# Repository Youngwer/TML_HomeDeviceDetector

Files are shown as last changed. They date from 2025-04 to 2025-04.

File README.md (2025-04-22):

# Home Device Detector

This project implements an embedded sound recognition system that assists Deaf and hard of hearing (DHH) individuals🧏 by detecting and classifying critical household sounds (smoke alarms and doorbells) and providing visual alerts through LEDs.

## Project Overview

The Home Device Detector addresses accessibility barriers for DHH individuals in smart homes by developing a TinyML-based embedded system that can:

- Detect critical household sound events in real-time⏰
- Classify between normal ambient sounds, doorbell rings🔔, and smoke alarms🚨
- Provide immediate visual feedback through color-coded LED indicators💡
- Process audio locally for enhanced privacy and reduced latency

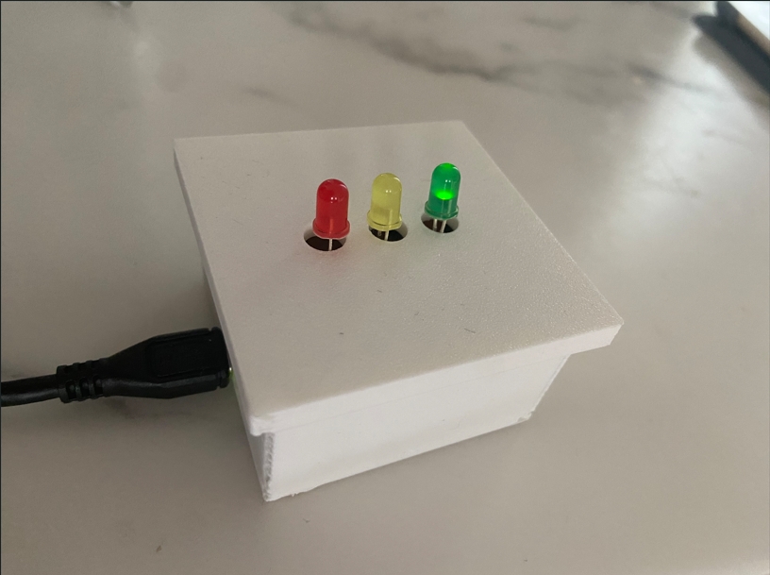
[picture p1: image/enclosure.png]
en


### Features

- Real-time detection of 3 sound categories:
  - Normal environmental sounds
  - Doorbell rings
  - Smoke alarms
- Visual feedback through LED indicators:
  - Green🟩 for normal environment
  - Yellow🟨 for doorbell alerts
  - Red🟥for smoke alarm detection
- Fast response time (within 2 seconds)
- Compact 3D-printed enclosure for easy placement
- Serial monitoring interface for debugging

## Hardware Requirements

- Arduino Nano 33 BLE Sense
- 3× LEDs (Green, Yellow, Red)
- 3× 220Ω resistors
- Breadboard or stripboard circuit connections
- 3D-printed enclosure (optional)
- USB cable for power and programming

## Software Dependencies and Resources

- Arduino IDE
- [Autodesk Fusion](https://www.autodesk.com/uk/products/fusion-360/overview?term=1-YEAR&tab=subscription) (for 3D modeling)
- [PrusaSlicer](https://www.prusa3d.com/page/prusaslicer_424/)(for 3D printing)
- [Edge Impulse](https://edgeimpulse.com/) Platform
- Librarys like [ArduinoBLE](https://docs.arduino.cc/libraries/arduinoble/) and [PDM.h](https://github.com/adafruit/Adafruit_ZeroPDM)
- Model library exported from Edge Impulse for [Home Device Detector](/ei-homedevicedetector-arduino-1.0.21.zip)

## Installation

1. Clone this repository:

   ```
   git clone https://github.com/Youngwer/TML_HomeDeviceDetector.git
   ```

2. Open the Arduino sketch [(`TML_HomeDeviceDetector.ino`)](/TML_HomeDeviceDetector/TML_HomeDeviceDetector.ino) in the Arduino IDE.

3. Install the required libraries through the Arduino IDE via:

Sketch > Include Library > Add .ZIP Library>ei-homedevicedetector-arduino-1.0.21.zip

4. The Edge Impulse model is already included in the repository as the `HomeDeviceDetector_inferencing` library. If you want to modify or retrain the model:

   - Create an account on [Edge Impulse](https://studio.edgeimpulse.com/)
   - Follow the instructions in the report to recreate the model
   - Export the model as an Arduino library
   - Replace the existing model files in the repository

5. Connect the hardware components according to the circuit diagram shown below:

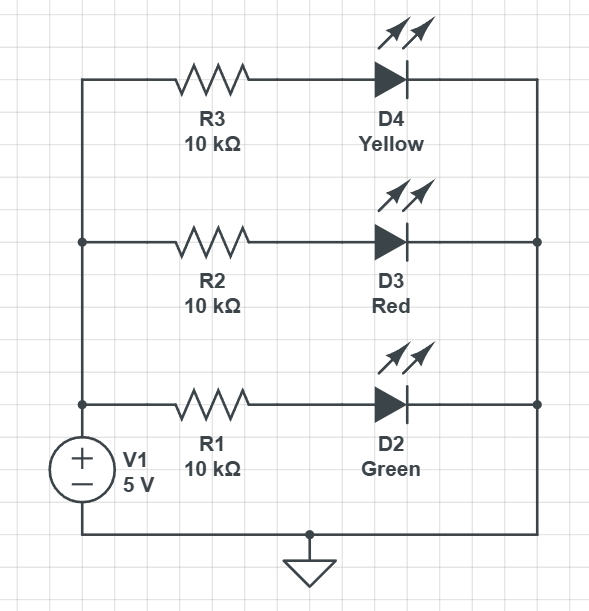
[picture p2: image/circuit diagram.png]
circuit diagram

   - Connect the Green LED to pin D2 through a 10kΩ resistor
   - Connect the Yellow LED to pin D3 through a 10kΩ resistor
   - Connect the Red LED to pin D4 through a 10kΩ resistor

6. Upload the sketch to your Arduino Nano 33 BLE Sense.

## Usage

Once the system is powered on and initialized:

1. The device will continuously monitor ambient sounds through the onboard microphone.
2. When a sound event is detected, the corresponding LED will illuminate:
   - Green LED: Normal environmental sounds
   - Yellow LED: Doorbell detection (with distinctive blinking pattern)
   - Red LED: Smoke alarm detection (with rapid blinking pattern)
3. Connect to the serial monitor (115200 baud) to view detailed classification results and debugging information.

## System Architecture

The system is implemented in a single Arduino sketch file:

- **TML_HomeDeviceDetector.ino** - Contains all functionality including audio capture, processing, inference, and LED control

This monolithic approach simplifies the codebase while still providing clear organization through different code sections and functions.

### Data Processing Pipeline

1. Continuous audio sampling through built-in microphone on the board
2. Pre-processing of audio data (windowing, normalization)
3. Feature extraction using Mel-Frequency Energy (MFE) spectrograms
4. Inference using the quantized TensorFlow Lite model
5. Classification of sound events based on confidence thresholds
6. Visual feedback through LED indicators

Below is a diagram show how the system work.

workflow
## Model Training

The model was trained using Edge Impulse with the following workflow:

1. Data collection from multiple sources:
   - Online audio repositories for doorbell and smoke alarm sounds
   - Smartphone recordings for ambient environmental sounds

2. Dataset preparation with balanced class distribution:
   - Smoke alarm: 1 minute 42 seconds
   - Doorbell sounds: 1 minute 50 seconds
   - Normal environmental audio: 1 minute 56 seconds
   - 80:20 train/test split

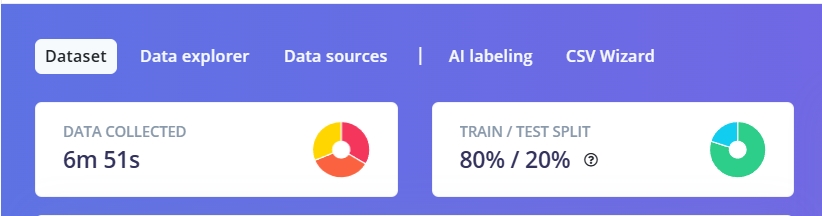
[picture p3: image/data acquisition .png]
dataset


3. Feature extraction using MFE spectrograms:
   - Window size: 1000ms
   - Window increase: 500ms
   - Sampling rate: 16kHz
   - 48 filters and 2048 FFT length

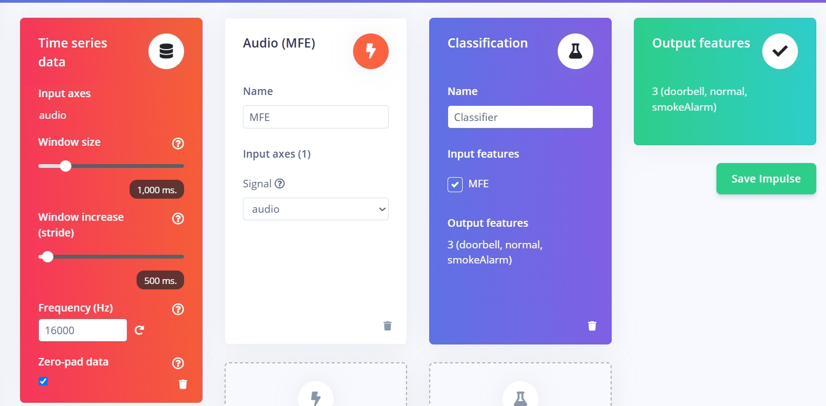
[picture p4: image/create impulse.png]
MFE

4. Neural network architecture:
   - Convolutional layers with optimized filter configurations
   - Dropout regularization to prevent overfitting
   - Dense layers for final classification

neural network
5. Model optimization and quantization:
   - Final accuracy: 94.9% (training), 90.32% (testing)
   - Model size optimized for Arduino deployment
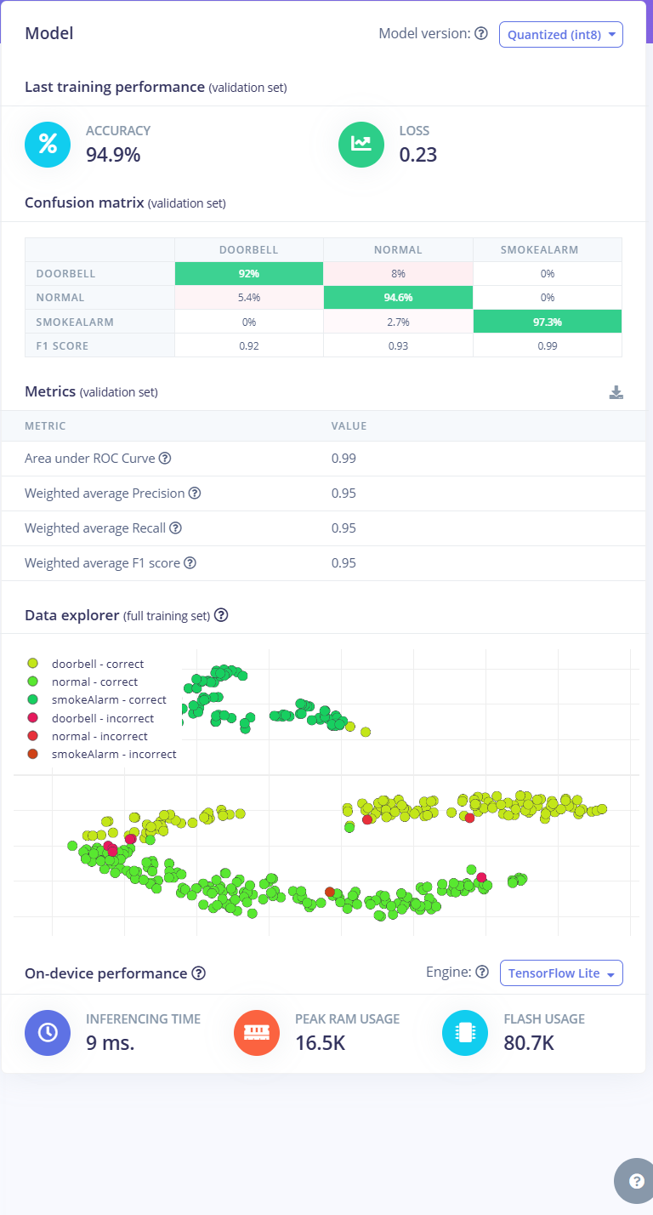
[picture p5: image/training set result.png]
training set result


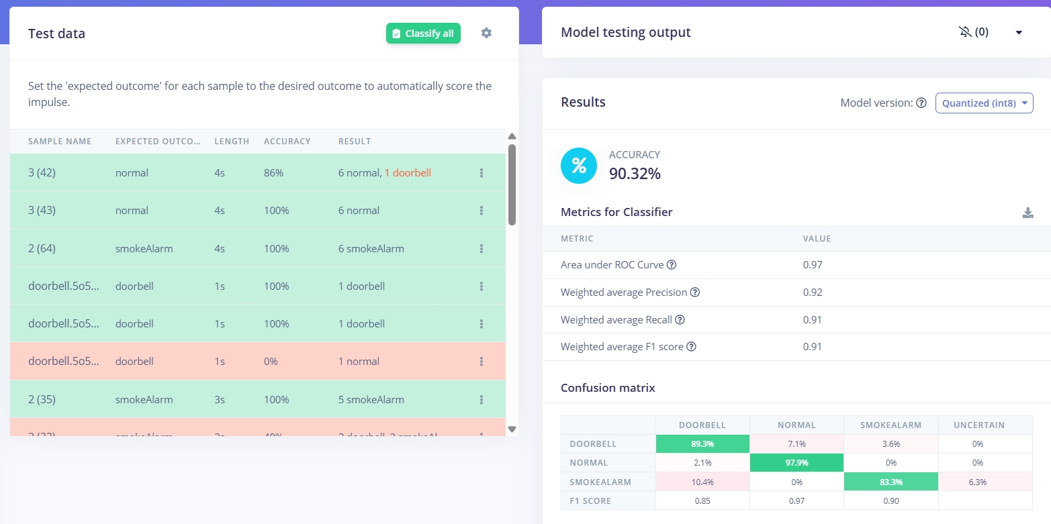
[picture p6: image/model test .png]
test result

## Calibration and Tuning

The system uses a confidence threshold parameter that can be adjusted in the code:

```cpp
#define CONFIDENCE_THRESHOLD 0.8 //80% confidence threshold
```

This threshold determines how confident the model must be to trigger an alert. You can adjust this value (between 0.0 and 1.0) based on your specific environment to balance between sensitivity and false positives.

## Performance

The system:

- Samples audio continuously at 16kHz
- Processes audio in 1-second windows
- Delivers visual alerts within 2 seconds of sound detection
- Achieves over 90% accuracy in sound classification
- Uses approximately 65% of the Arduino's available memory

The signal processing approach uses a sliding window with prediction smoothing:

```cpp
// Smooth prediction results
static float normal_prob_avg = 0.0;
static float doorbell_prob_avg = 0.0;
static float smokealarm_prob_avg = 0.0;
static int prediction_count = 0;

// In the loop
// Smooth prediction results
normal_prob_avg = (normal_prob_avg * prediction_count + normal_prob) / (prediction_count + 1);
doorbell_prob_avg = (doorbell_prob_avg * prediction_count + doorbell_prob) / (prediction_count + 1);
smokealarm_prob_avg = (smokealarm_prob_avg * prediction_count + smokealarm_prob) / (prediction_count + 1);
prediction_count++;
if (prediction_count >= EI_CLASSIFIER_SLICES_PER_MODEL_WINDOW) {
    prediction_count = 0;
}
```
When device detects home device sound like doorbell, the serial monitor will print information shown below

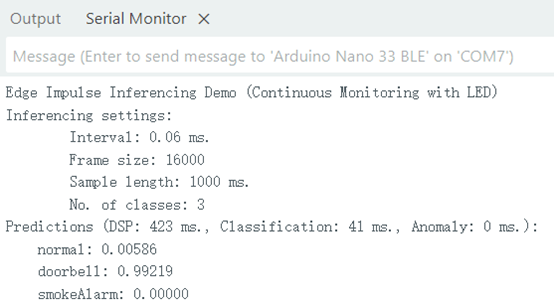
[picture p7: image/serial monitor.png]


## Enclosure Design

The 3D-printed enclosure was designed using Fusion 360 and includes:

- Mounting points for the Arduino Nano 33 BLE Sense
- Openings for the USB connection
- Optimal positioning for the onboard microphone
- Diffusion windows for the LED indicators

[STL files](/3D%20Model/HomeSoundDetector.stl) for the enclosure are included in the `/3D Model` folder.

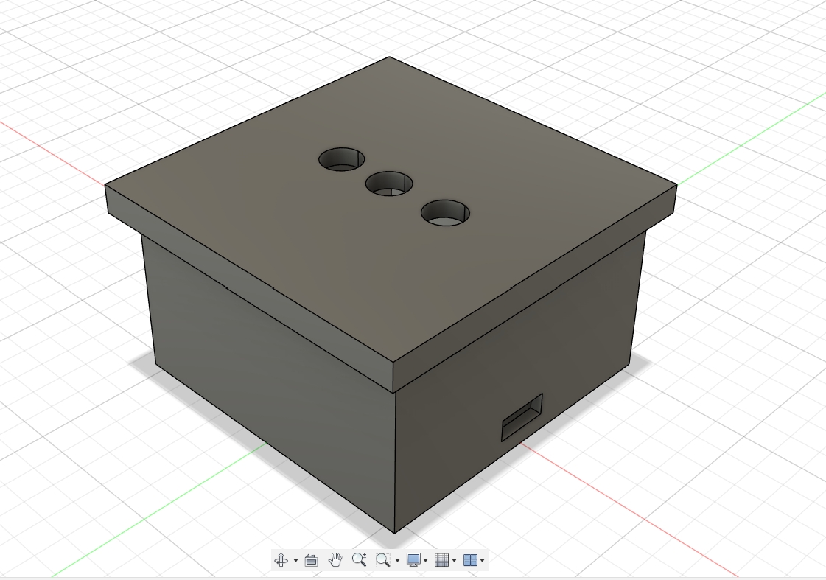
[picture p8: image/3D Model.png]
3D Model

## Troubleshooting

- If the LEDs don't illuminate, check your connections and resistor values
- If certain sounds aren't recognized correctly, try adjusting the confidence threshold
- If the device becomes unresponsive, check the serial monitor for memory-related errors
- Ensure the microphone opening in the enclosure isn't obstructed

## Future Improvements

- Add support for more household sound categories (microwave, kettle, etc.)
- Implement haptic feedback through vibration motors
- Add Bluetooth connectivity for smartphone notifications
- Develop adaptive audio filtering for noisy environments
- Include a battery power option for portable use

## Acknowledgments

- UCL Centre for Advanced Spatial Analysis ([CASA](https://www.ucl.ac.uk/bartlett/casa))
- Edge Impulse for the embedded machine learning platform
- Arduino community for libraries and support
- Online sound repositories ([Pixabay](https://pixabay.com/sound-effects/), [Uppbeat](https://uppbeat.io/sfx)) for training data

## Author

Wenhao Yang - [GitHub](https://github.com/Youngwer)

------

Project created as part of the CASA0018 - Deep Learning for Sensor Networks course at University College London.

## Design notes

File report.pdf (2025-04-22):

# CASA0018 Deep Learning for Sensor Networks

# Coursework Report

# Home Device Detector

Word count: 1780

GitHub URL: https://github.com/Youngwer/TML_HomeDeviceDetector

Declaration of Authorship

I, Wenhao Yang, confirm that the work presented in this assessment is my own. Where information has been derived from other sources, I confirm that this has been indicated in the work.

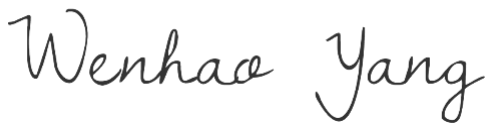
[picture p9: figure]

2025/4/21

# 1.Introduction

## 1.1 Project Background and Motivation

The rise of smart homes, powered by Internet of Things (IoT) technologies, has dramatically transformed domestic environments. Especially, the integration of Tiny Machine Learning (TinyML) into home appliances has opened new avenues for enhancing automation and user interaction by enabling efficient, on-device intelligence for resource-constrained IoT devices, (Mishra, Malche and Hirawat, 2024). However, Deaf and hard of hearing (DHH) individuals face challenges in benefiting from these technologies, as they cannot hear critical auditory cues from household devices, such as microwave, or oven timers, which limits their ability to fully use the safety and convenience of smart home appliances. (Jain et al., 2020). Therefore, there exists a need to develop inclusive smart home designs for the disabled to address these accessibility barriers.

## 1.2 Project Overview and Purpose

This project addresses these challenges by developing an embedded sound recognition system named HomeDeviceDetector, which leverages a TinyML model trained on Edge Impulse and deployed and on an Arduino Nano BLE Sense to detect and classify home sound events, such as smoke alarms and doorbells, delivering real-time visual alerts via LEDs (within 2 seconds) for DHH users.

## 1.3 Research Question

How can the device accurately detect and classifies critical household sound events on resource-constrained Arduino devices?

## 1.4 Prior Work and Technical Background

Research has demonstrated TinyML’s potential in smart homes through applications like keyword spotting for voice-based automation, achieving high accuracy in resource-constrained environments(Mishra, Malche and Hirawat, 2024). Additionally, studies have explored sound awareness systems called HomeSound for DHH users, using visual and haptic feedback to convey information of household sounds(Jain et al., 2020). Furthermore, TinyML has been applied in wearable IoT devices for sign language recognition, translating gestures into verbal language for hearing-impaired users(Sharma, Gupta and Kumar, 2024). Furthermore, Edge Impulse enables for embedded machine learning (ML) development, offering an open-source machine learning and signal processing platform in a low-power embedded environment with excellent data security and privacy protection by processing voice locally(Koo and Seo, 2023).

# 2. Project Configuration and Methodology

## 2.1 Hardware Configuration

## Hardware Components

Arduino Nano 33 BLE Sense:
As the core processing unit, which is an ideal for running TinyML models while maintaining low power consumption.
Visualisation part:
it consists of three LEDs:
⚫ | Green for normal environment;
⚫ | Red for smoke alarm detection;
⚫ | Yellow for doorbell alerts.
The circuit diagram is shown in Figure 1 below.

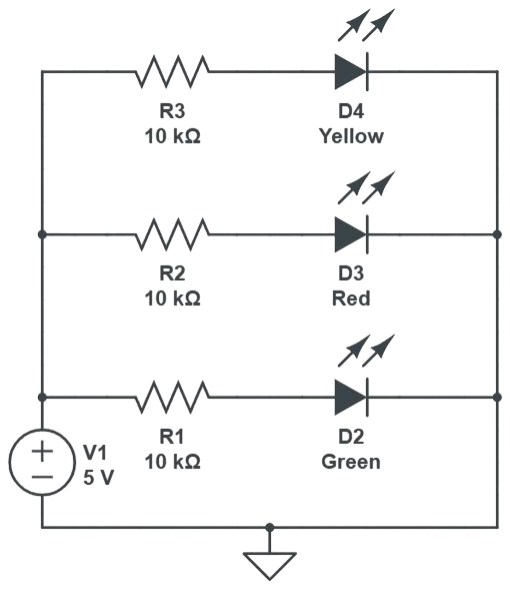
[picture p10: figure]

Figure 1. Circuit Diagram

## Enclosure

The enclosure was designed to be compact using Fusion 360 for 3D modeling and PrusaSlicer for preparing the print, which also includes precise openings for the USB connection and optimal positioning for the onboard microphone to capture audio effectively. Below shows the simple enclosure in Figure 2.

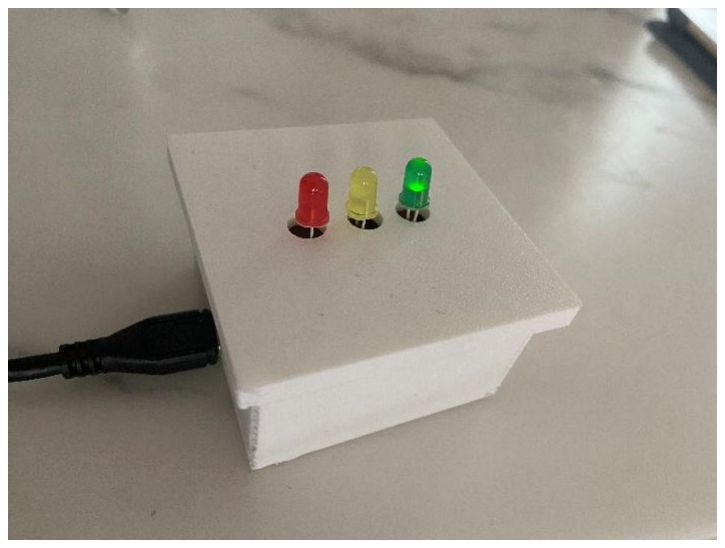
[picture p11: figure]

Figure 2. Simple Enclosure

## 2.2 Data Collection and Processing

## Data Collection Strategy

Due to the impracticality of collecting real-time smoke alarm sounds (which would be potentially dangerous in a home environment), audio samples for both doorbell and smoke alarm categories were sourced from online repositories(Pixabay; Uppbeat) in WAV format. To better simulate real-world conditions with environmental noise, some doorbell samples were recorded using my mobile phone, which intentionally introduced background noise to improve model robustness.
For the "normal" category, smartphone recordings captured typical household acoustic environments, including conversation, mouse clicks and other ambient noises, which help the model distinguish between everyday sounds and the target events.

## Methodology

The audio processing workflow adopts a structured approach, beginning with the collection of raw audio samples, followed by feature extraction through the conversion of raw audio into Mel-Frequency Energy (MFE) spectrograms to capture frequency characteristics. Subsequently, a convolutional neural network architecture is implemented for model training to enable audio classification, and finally, the trained model undergoes quantization and optimization for deployment on an Arduino platform.
Figure 3 shows the overall workflow of the Home Device Detector.

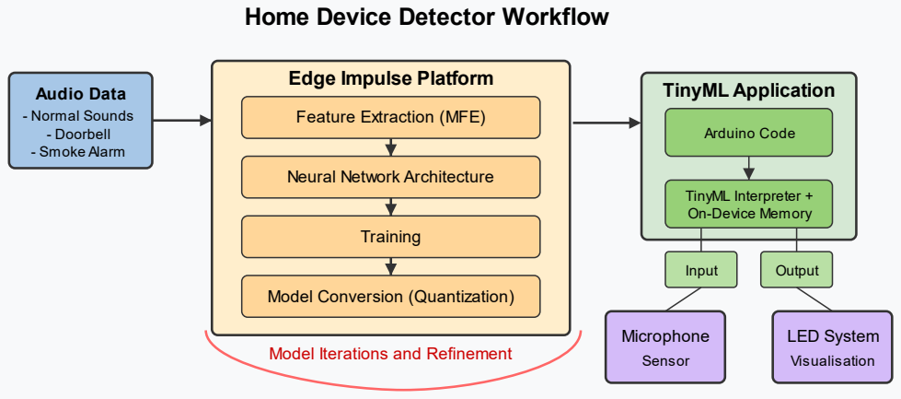
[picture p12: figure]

Figure 3. Workflow of Home Device Detector

# 3 Edge Impulse Development

## 3.1 Data Acquisition and Balancing

Building on the data collection strategy outlined previously, the practical implementation on Edge Impulse began with uploading and organizing the audio samples for model training. Most doorbell sounds were trimmed to approximately 1 second duration, while normal environmental sounds and smoke alarm samples were initially kept longer at 3-5 seconds.

## Challenge: Data Imbalance

During early testing, a significant challenge emerged that severely impacted model performance. The initial dataset contained highly unbalanced class distributions, the audio length of smoke alarm and Doorbell sounds is 1min 56s and 1min 18s respectively.
This imbalance resulted in poor model performance with testing accuracy only reaching approximately 70%.

## Solution: Balancing Class Distribution

I carefully adjusted the dataset to achieve better balance between classes. The final training dataset contained more equalized durations:
- Smoke alarm audio: 1 minute 42 seconds
- Doorbell sounds: 1 minute 50 seconds
- Normal environmental audio: 1 minute 56 seconds
This balanced dataset was then split into training and testing sets with an 80:20 ratio, ensuring that each set contained a representative distribution of all three sound categories, which is shown below in Figure 4.

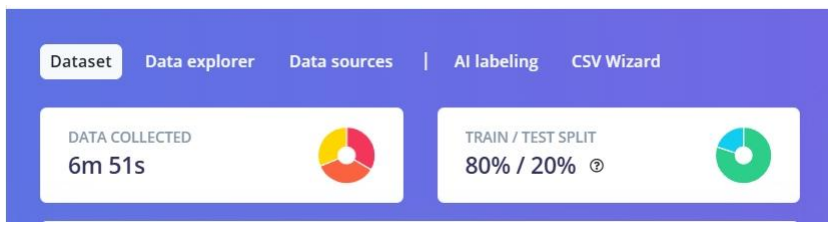
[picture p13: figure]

Figure 4. Dataset of Audio

## 3.2 Creating the Impulse

The next step is to creating an "impulse" - the sequence of processing blocks that transform raw sensor data into classification outputs. The figure 5 below shows the overview of the impulse.

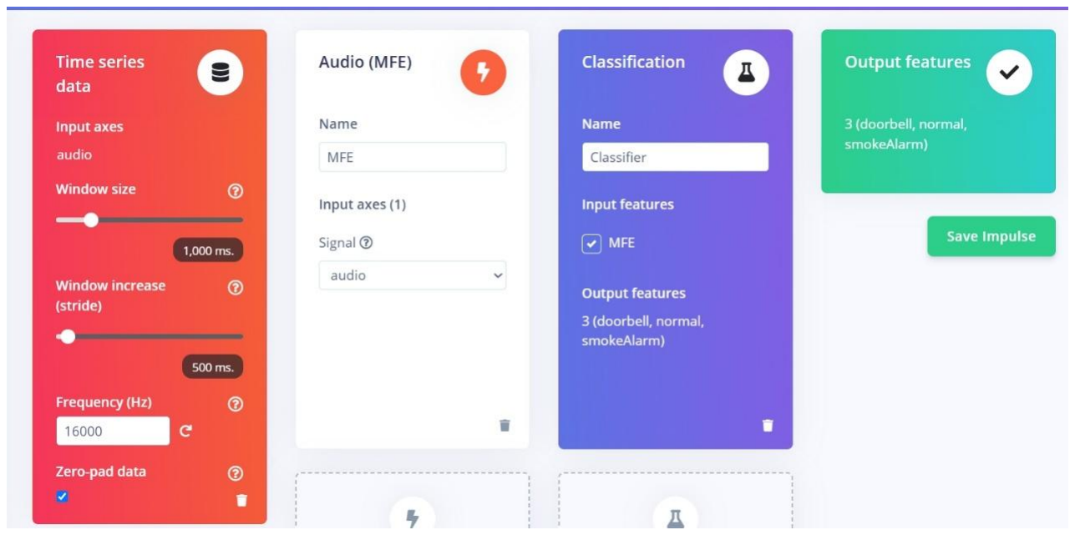
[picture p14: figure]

Figure 5. ”Create Impulse” Overview

## Time Series Data Configuration

The first step was configuring the time series data parameters:
- Window size: 1000ms
- Window increase: 500ms
- Frequency: 16kHz sampling rate (avoid to be too high)
This configuration resulted in 16,000 sample points per window, which was determined to be an optimal balance between capturing sufficient audio information and staying within the memory limitations of the target device.

## Challenge: Memory Allocation Failure

After completing initial model training and attempting to deploy to the Arduino device, I encountered a technical obstacle. The serial monitor displayed the following error messages: Failed to start PDM! ERR: Could not allocate audio buffer (size 48000), this could be due to the window length of your model

This error indicated a memory allocation failure on the device. The Arduino Nano 33 BLE Sense with only 256KB of SRAM could not allocate a buffer for 48,000 sample points (3 seconds at 16kHz).

## Solution: Parameter Optimization

To resolve this deployment issue, I reconfigured the impulse with smaller parameters that would fit within the device's memory constraints, such as decrease the window size to 1 seconds:

## Processing Block Selection and Configuration

I selected the Mel-frequency Energy (MFE) spectral features extraction method due to its effectiveness in capturing relevant frequency characteristics while requiring less computational resources; For the learning block, I selected the Keras Classification.
I optimized the MFE parameters for better feature separation, the most important parameter adjustment is the increase of filter number (from 24 to 48) and FFT length (from 1024 to 2048) which helped achieve better separation between the features of different sound classes, which is shown in figures 6 and 7.

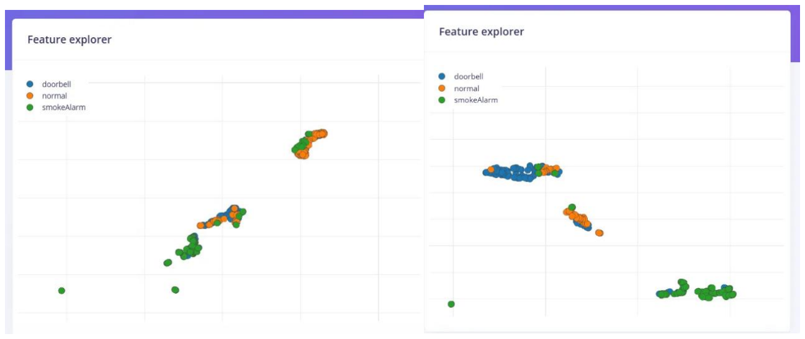
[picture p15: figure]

Figure 6. Audio Data Diagram with Default Parameters
Figure 7. Audio Data Diagram with Refined Parameters

## 3.3 Neural Network Architecture and Training

After configuring the time series data parameters and MFE processing block, the next crucial step was designing and training the neural network classifier - the core of the sound recognition system.

## Neural Network Architecture

For classification, I implemented a Convolutional Neural Network (CNN) architecture specifically optimized for audio pattern recognition, which is shown below in Figure 8.

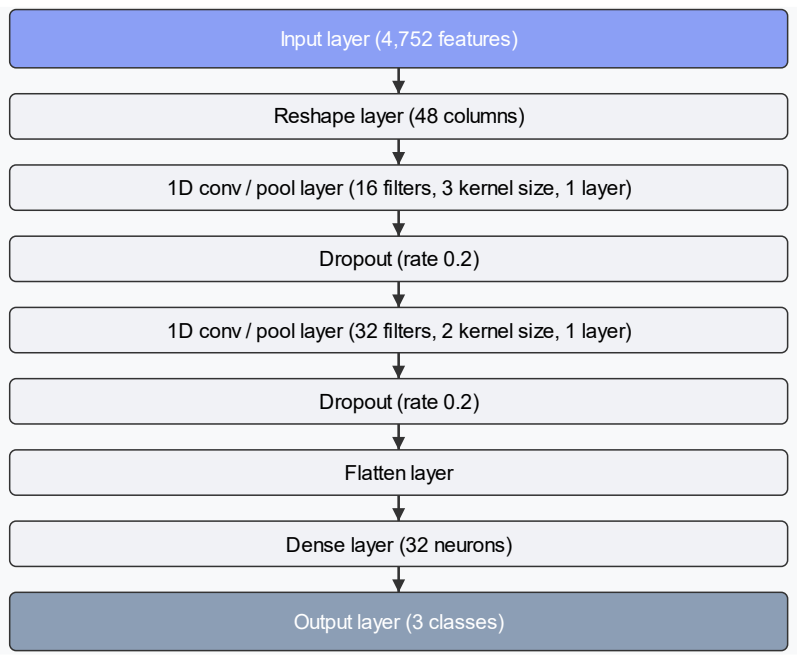
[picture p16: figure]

Figure 8. Neural Network Architecture of Home Sound Detector

## Iterative Model Training Process and Test

Initial Configuration
- Training epochs: 50
- Learning rate: 0.001
- Data augmentation: Enabled with low noise addition
- Initial results: 86.9% accuracy with 0.45 loss
Training Duration Optimization
I Increased training epochs from 50 to 100 and the results improve to 88.9% accuracy with 0.38 loss. It demonstrated that the model benefited from additional training iterations. Regularization Fine-tuning
I adjust both dropout layers to 0.2 (from default values), which reduce over-regularization issues. Through experiment with dropout rates ±0.05, I confirming 0.2 as optimal. Architecture Enhancement
Later, dense layer was added after the flatten layer, and filter configuration was optimized((16 filters in first layer, 32 filters in the second)), which significantly improved accuracy to 94.9% with 0.25 loss, which is shown in Figure 9 below

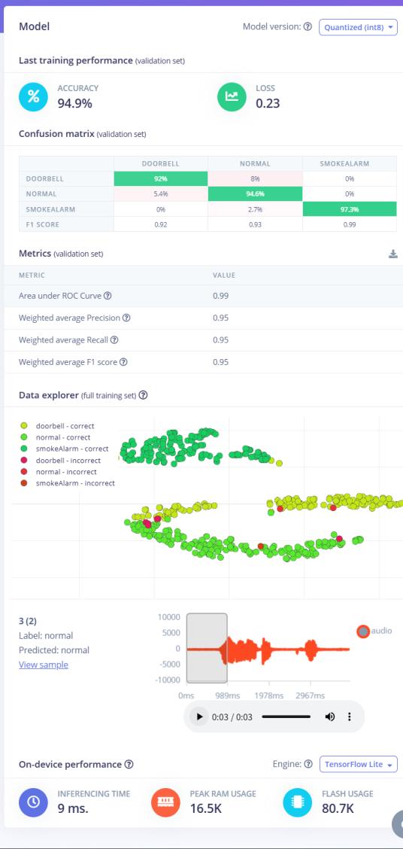
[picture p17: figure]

Figure 9 Training Set Result Addressing Overfitting and Refine in Test Set
Despite the high training accuracy, I observed suboptimal performance on the test set, indicating potential overfitting and limited generalization ability.
To address this issue, I Adjust kernel sizes in the 1D convolutional layers (3 for first layer, 2 for second), which can improve the model's ability to capture relevant audio patterns without memorizing training data. Therefore, test set performance is enhanced over 90% accuracy, which is shown below in Figure 10.

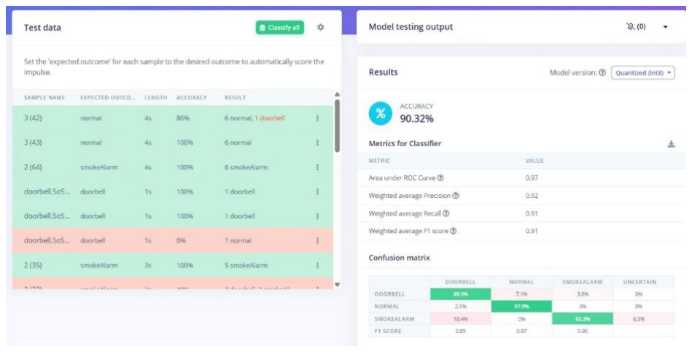
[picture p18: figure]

Figure 10. Testing Set Results The final model achieved over 94% accuracy on the training set and demonstrated good generalization capability on the test set, meeting the project's target threshold for a safety-critical application.

# 4. Arduino Deployment and Implementation

The next phase was deploying it to the Arduino Nano 33 BLE Sense device and implementing the code to handle audio processing, inference, and visual feedback.

## 4.1 Model Export and Deployment

The trained model was exported from Edge Impulse as an Arduino library package (HomeDeviceDetector_inferencing.h), which included the quantized TensorFlow Lite model, pre-processing code, and an inference runner optimized for the ARM Cortex-M4 processor.

## 4.2 Arduino Code Implementation

The implementation focuses on continuous audio monitoring with specific optimizations for reliable detection:

## Audio Capture and Buffering

typedef struct {

signed short *buffers[2];

unsigned char buf_select;

unsigned char buf_ready;

unsigned int buf_count;

unsigned int n_samples;

} inference_t;
This double-buffering approach allows continuous audio capture while processing the previously recorded segment, ensuring no sound events are missed.

## LED Visual Feedback System

The visual feedback is implemented with distinctive blinking patterns for each sound type:

void update_leds(float normal_prob, float doorbell_prob, float smokealarm_prob) {

if (normal_prob >= CONFIDENCE_THRESHOLD) {

digitalWrite(LED_NORMAL, HIGH);

} else {

digitalWrite(LED_NORMAL, LOW);

}

if (doorbell_prob >= CONFIDENCE_THRESHOLD) {

digitalWrite(LED_DOORBELL, HIGH);

for (int i = 0; i < 3; i++) {

digitalWrite(LED_DOORBELL, LOW);

delay(100);

digitalWrite(LED_DOORBELL, HIGH);

delay(100);

}

} else {

digitalWrite(LED_DOORBELL, LOW);

}

if (smokealarm_prob >= CONFIDENCE_THRESHOLD) {

digitalWrite(LED_SMOKEALARM, HIGH);

for (int i = 0; i < 5; i++) {

digitalWrite(LED_SMOKEALARM, LOW);

delay(50);

digitalWrite(LED_SMOKEALARM, HIGH);

delay(50);

}

} else {

digitalWrite(LED_SMOKEALARM, LOW);

}

}
This creates unique visual patterns:
- Normal sounds: Steady green light
- Doorbell: Yellow light
- Smoke alarm: Red light

When the device detects doorbell, the serial monitor reacts like:

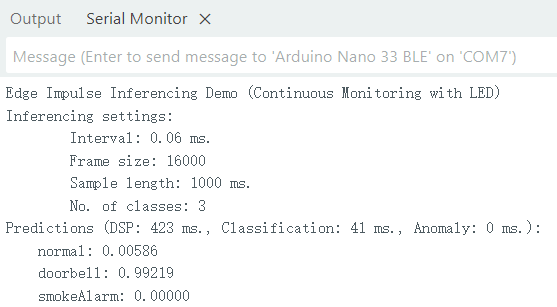
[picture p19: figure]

Figure 11. Serial Monitor Output

## 4.3 Implementation Challenges

Key challenges in the code implementation included: memory management within the Arduino's limited resources, and finding the optimal confidence threshold (set at 80%).

The final implementation successfully achieved reliable sound event detection with visual feedback within the targeted response time, making it suitable for assisting DHH individuals in home environments.

# 5. Results and Evaluation

## 5.1 Results

After multiple iterations of development, the final model achieved 94.9% training accuracy and 90.32% testing accuracy with a loss of 0.23. The confusion matrix showed strong classification capabilities, with most misclassifications occurring between doorbell and smoke alarm classes due to acoustic similarities.

## 5.2 Critical Reflection and Experience Learnt

There are several valuable experiences I gained through this coursework.
First, data balance proved crucial - an early iteration with imbalanced classes achieved only 70% accuracy, while the balanced dataset dramatically improved performance; Second, overfitting is easy to happen and preventing overfitting is important and necessary to increase generalization ability of the model.

The system still has several limitations. In real-world testing, the device occasionally enters an "uncertain" state where no LEDs illuminate. Certain sounds in household music sometimes trigger false doorbell detections. The acoustic similarity between some doorbell and smoke alarm sounds leads to occasional misclassifications.

Future improvements could include expanding the dataset with more diverse samples to adding other important household sound categories, and solved the mis-triggering problems with more sophisticated test work and logic design.

# 6. Conclusion

The HomeDeviceDetector successfully demonstrates how TinyML can create practical assistive technology for DHH individuals. The system addresses an important accessibility gap while showcasing the potential of embedded ML to deliver specialized solutions where traditional cloud-based approaches might be impractical.

# Bibliography

Jain, D. et al. (2020) ‘HomeSound: An Iterative Field Deployment of an In-Home Sound Awareness System for Deaf or Hard of Hearing Users’, in Proceedings of the 2020 CHI Conference on Human Factors in Computing Systems. CHI ’20: CHI Conference on Human Factors in Computing Systems, Honolulu HI USA: ACM, pp. 1–12. Available at: https://doi.org/10.1145/3313831.3376758.

Koo, G.-S. and Seo, Y.G. (2023) ‘Performance Analysis of Speech Processing Techniques Using Edge Impulse’, Journal of Digital Contents Society, 24(6), pp. 1327–1338. Available at: https://doi.org/10.9728/dcs.2023.24.6.1327.

Mishra, J., Malche, T. and Hirawat, A. (2024) ‘Embedded Intelligence for Smart Home Using TinyML Approach to Keyword Spotting’, in ECSA-11. ECSA-11, MDPI, p. 30. Available at: https://doi.org/10.3390/ecsa-11-20522.

Pixabay ‘Door Bell Sound’. Available at: https://pixabay.com/sound-effects/search/door-bell/(Accessed: 12 April 2025).

Sharma, S., Gupta, R. and Kumar, A. (2024) ‘A TinyML solution for an IoT-based communication device for hearing impaired’, Expert Systems with Applications, 246, p. 123147. Available at: https://doi.org/10.1016/j.eswa.2024.123147.

Uppbeat ‘Smoke Alarm Sound’. Available at: https://uppbeat.io/sfx/category/alarm/smokealarm (Accessed: 12 April 2025).

# AI Use Acknowledgment

I acknowledge the use of Claude (3.7 Sonnet, https://claude.ai/new) as an assistive tool in accordance with UCL's Category 2 guidelines. Specifically:
1. To receive structural suggestions for the report.
Prompts used: My report is about a device to detect home sound designed for DDH people in smart homes base on Edge Impulse, give me the outline of the report.
2. To ensure grammar and style consistency.
Prompts used: Check the grammar of the report and correct the wrong one and some sentence with unclear expression.
All content, analysis, and ideas presented are my own, and AI was used solely as a supportive resource, not to generate original ideas or replace my own work.

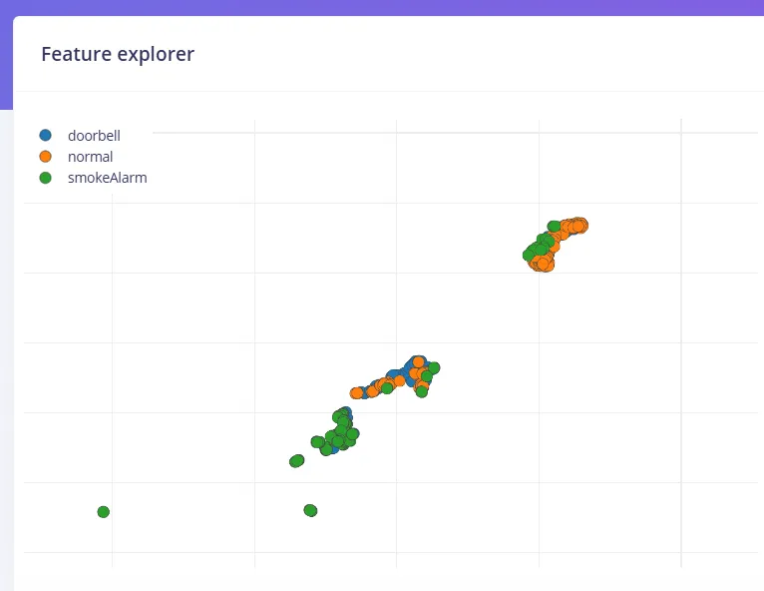
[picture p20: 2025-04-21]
image/MFE_pre.webp

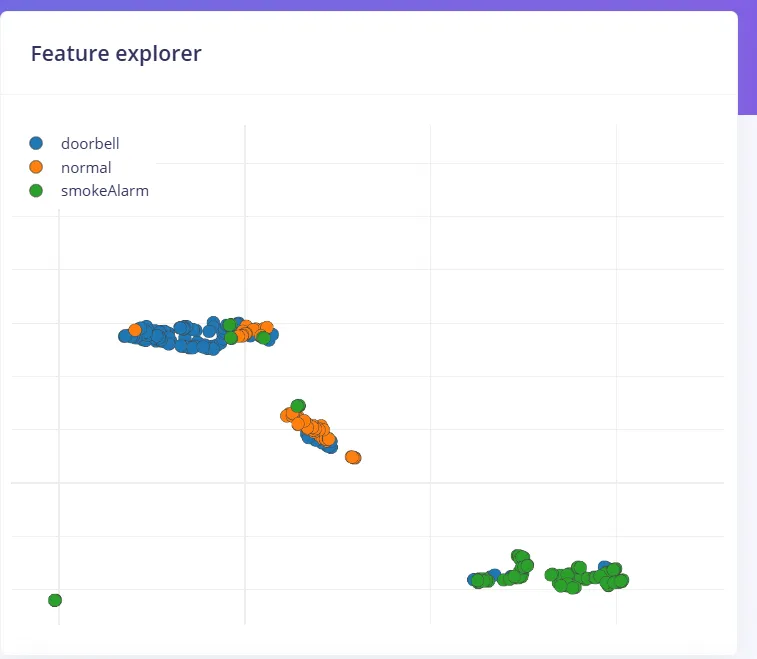
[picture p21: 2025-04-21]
image/MFE_later.webp

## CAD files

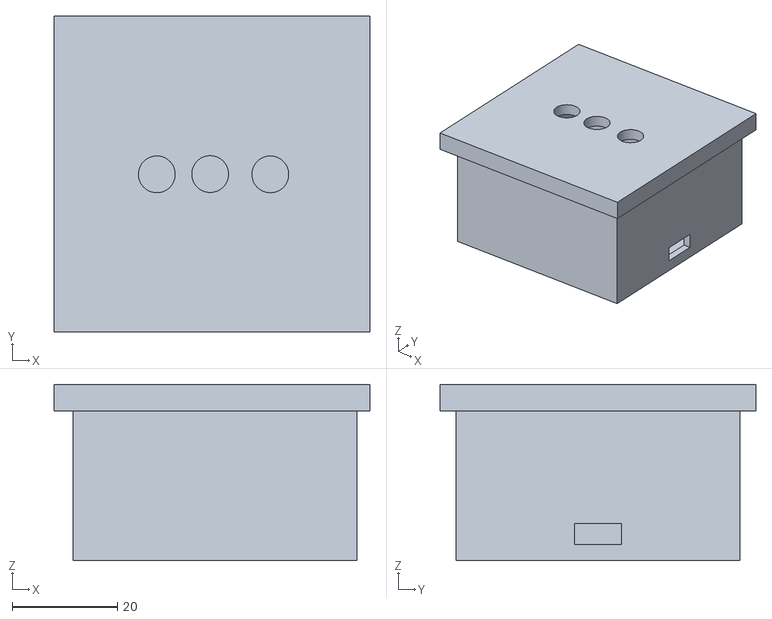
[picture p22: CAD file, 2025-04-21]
3D Model/HomeSoundDetector.stl
60.0 x 60.0 x 33.4

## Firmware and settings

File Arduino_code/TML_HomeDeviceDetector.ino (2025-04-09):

/* Edge Impulse ingestion SDK
 * Copyright (c) 2022 EdgeImpulse Inc.
 *
 * Licensed under the Apache License, Version 2.0 (the "License");
 * you may not use this file except in compliance with the License.
 * You may obtain a copy of the License at
 * http://www.apache.org/licenses/LICENSE-2.0
 *
 * Unless required by applicable law or agreed to in writing, software
 * distributed under the License is distributed on an "AS IS" BASIS,
 * WITHOUT WARRANTIES OR CONDITIONS OF ANY KIND, either express or implied.
 * See the License for the specific language governing permissions and
 * limitations under the License.
 */

// If your target is limited in memory remove this macro to save 10K RAM
#define EIDSP_QUANTIZE_FILTERBANK   0

/**
 * Define the number of slices per model window.
 */
#define EI_CLASSIFIER_SLICES_PER_MODEL_WINDOW 2 // 减少到 2，片段时长 1 秒

/* Includes ---------------------------------------------------------------- */
#include <PDM.h>
#include <HomeDeviceDetector_inferencing.h>

// LED pin definitions
#define LED_NORMAL D2      // 绿灯 - 正常状态
#define LED_SMOKEALARM D3  // 红灯 - 烟雾报警器
#define LED_DOORBELL D4    // 黄灯 - 门铃

// 设置分类判断的阈值
#define CONFIDENCE_THRESHOLD 0.8  // 60%的置信度阈值

/** Audio buffers, pointers and selectors */
typedef struct {
    signed short *buffers[2];
    unsigned char buf_select;
    unsigned char buf_ready;
    unsigned int buf_count;
    unsigned int n_samples;
} inference_t;

static inference_t inference;
static bool record_ready = false;
static signed short *sampleBuffer;
static bool debug_nn = false; // Set this to true to see e.g. features generated from the raw signal
static int print_results = -(EI_CLASSIFIER_SLICES_PER_MODEL_WINDOW);

// 平滑预测结果
static float normal_prob_avg = 0.0;
static float doorbell_prob_avg = 0.0;
static float smokealarm_prob_avg = 0.0;
static int prediction_count = 0;

/**
 * @brief      Arduino setup function
 */
void setup()
{
    Serial.begin(115200);
    while (!Serial);
    Serial.println("Edge Impulse Inferencing Demo (Continuous Monitoring with LED)");

    // 初始化LED引脚
    pinMode(LED_NORMAL, OUTPUT);
    pinMode(LED_SMOKEALARM, OUTPUT);
    pinMode(LED_DOORBELL, OUTPUT);
    
    // 初始状态下关闭所有LED
    digitalWrite(LED_NORMAL, LOW);
    digitalWrite(LED_SMOKEALARM, LOW);
    digitalWrite(LED_DOORBELL, LOW);

    // 打印推理设置
    ei_printf("Inferencing settings:\n");
    ei_printf("\tInterval: %.2f ms.\n", (float)EI_CLASSIFIER_INTERVAL_MS);
    ei_printf("\tFrame size: %d\n", EI_CLASSIFIER_DSP_INPUT_FRAME_SIZE);
    ei_printf("\tSample length: %d ms.\n", EI_CLASSIFIER_RAW_SAMPLE_COUNT / 16);
    ei_printf("\tNo. of classes: %d\n", sizeof(ei_classifier_inferencing_categories) /
                                            sizeof(ei_classifier_inferencing_categories[0]));

    run_classifier_init();
    if (microphone_inference_start(EI_CLASSIFIER_SLICE_SIZE) == false) {
        ei_printf("ERR: Could not allocate audio buffer (size %d), this could be due to the window length of your model\r\n", EI_CLASSIFIER_RAW_SAMPLE_COUNT);
        return;
    }
}

/**
 * @brief      更新LED状态
 */
void update_leds(float normal_prob, float doorbell_prob, float smokealarm_prob) {
    if (normal_prob >= CONFIDENCE_THRESHOLD) {
        digitalWrite(LED_NORMAL, HIGH);
    } else {
        digitalWrite(LED_NORMAL, LOW);
    }
    
    if (doorbell_prob >= CONFIDENCE_THRESHOLD) {
        digitalWrite(LED_DOORBELL, HIGH);
        for (int i = 0; i < 3; i++) {
            digitalWrite(LED_DOORBELL, LOW);
            delay(100);
            digitalWrite(LED_DOORBELL, HIGH);
            delay(100);
        }
    } else {
        digitalWrite(LED_DOORBELL, LOW);
    }
    
    if (smokealarm_prob >= CONFIDENCE_THRESHOLD) {
        digitalWrite(LED_SMOKEALARM, HIGH);
        for (int i = 0; i < 5; i++) {
            digitalWrite(LED_SMOKEALARM, LOW);
            delay(50);
            digitalWrite(LED_SMOKEALARM, HIGH);
            delay(50);
        }
    } else {
        digitalWrite(LED_SMOKEALARM, LOW);
    }
}

/**
 * @brief      Arduino main function. Runs the inferencing loop.
 */
void loop()
{
    bool m = microphone_inference_record();
    if (!m) {
        ei_printf("ERR: Failed to record audio...\n");
        return;
    }

    signal_t signal;
    signal.total_length = EI_CLASSIFIER_SLICE_SIZE;
    signal.get_data = microphone_audio_signal_get_data; // 修正为正确的函数名
    ei_impulse_result_t result = {0};

    EI_IMPULSE_ERROR r = run_classifier_continuous(&signal, &result, debug_nn);
    if (r != EI_IMPULSE_OK) {
        ei_printf("ERR: Failed to run classifier (%d)\n", r);
        return;
    }

    // 获取当前片段的预测概率
    float normal_prob = 0.0;
    float doorbell_prob = 0.0;
    float smokealarm_prob = 0.0;

    for (size_t ix = 0; ix < EI_CLASSIFIER_LABEL_COUNT; ix++) {
        if (strcmp(result.classification[ix].label, "normal") == 0) {
            normal_prob = result.classification[ix].value;
        }
        else if (strcmp(result.classification[ix].label, "doorbell") == 0) {
            doorbell_prob = result.classification[ix].value;
        }
        else if (strcmp(result.classification[ix].label, "smokeAlarm") == 0) {
            smokealarm_prob = result.classification[ix].value;
        }
    }

    // 平滑预测结果
    normal_prob_avg = (normal_prob_avg * prediction_count + normal_prob) / (prediction_count + 1);
    doorbell_prob_avg = (doorbell_prob_avg * prediction_count + doorbell_prob) / (prediction_count + 1);
    smokealarm_prob_avg = (smokealarm_prob_avg * prediction_count + smokealarm_prob) / (prediction_count + 1);
    prediction_count++;
    if (prediction_count >= EI_CLASSIFIER_SLICES_PER_MODEL_WINDOW) {
        prediction_count = 0;
    }

    // 只有在完整窗口（2 个片段）后才更新 LED 和打印结果
    if (++print_results >= EI_CLASSIFIER_SLICES_PER_MODEL_WINDOW) {
        // 打印预测结果（仅当检测到目标类别时）
        bool print = false;
        if (doorbell_prob_avg >= CONFIDENCE_THRESHOLD || smokealarm_prob_avg >= CONFIDENCE_THRESHOLD) {
            print = true;
        }
        if (print) {
            ei_printf("Predictions ");
            ei_printf("(DSP: %d ms., Classification: %d ms., Anomaly: %d ms.)",
                result.timing.dsp, result.timing.classification, result.timing.anomaly);
            ei_printf(": \n");
            ei_printf("    normal: %.5f\n", normal_prob_avg);
            ei_printf("    doorbell: %.5f\n", doorbell_prob_avg);
            ei_printf("    smokeAlarm: %.5f\n", smokealarm_prob_avg);
        }
        print_results = 0;

        // 更新 LED 状态
        update_leds(normal_prob_avg, doorbell_prob_avg, smokealarm_prob_avg);
    }
}

/**
 * @brief      PDM buffer full callback
 */
static void pdm_data_ready_inference_callback(void)
{
    int bytesAvailable = PDM.available();

    // read into the sample buffer
    int bytesRead = PDM.read((char *)&sampleBuffer[0], bytesAvailable);

    if (record_ready == true) {
        for (int i = 0; i < bytesRead >> 1; i++) {
            inference.buffers[inference.buf_select][inference.buf_count++] = sampleBuffer[i];

            if (inference.buf_count >= inference.n_samples) {
                inference.buf_select ^= 1;
                inference.buf_count = 0;
                inference.buf_ready = 1;
            }
        }
    }
}

/**
 * @brief      Init inferencing struct and setup/start PDM
 */
static bool microphone_inference_start(uint32_t n_samples)
{
    inference.buffers[0] = (signed short *)malloc(n_samples * sizeof(signed short));
    if (inference.buffers[0] == NULL) {
        return false;
    }

    inference.buffers[1] = (signed short *)malloc(n_samples * sizeof(signed short));
    if (inference.buffers[1] == NULL) {
        free(inference.buffers[0]);
        return false;
    }

    sampleBuffer = (signed short *)malloc((n_samples >> 1) * sizeof(signed short));
    if (sampleBuffer == NULL) {
        free(inference.buffers[0]);
        free(inference.buffers[1]);
        return false;
    }

    inference.buf_select = 0;
    inference.buf_count = 0;
    inference.n_samples = n_samples;
    inference.buf_ready = 0;

    // configure the data receive callback
    PDM.onReceive(&pdm_data_ready_inference_callback);

    PDM.setBufferSize(n_samples * sizeof(int16_t)); // 增大 PDM 缓冲区

    if (!PDM.begin(1, EI_CLASSIFIER_FREQUENCY)) {
        ei_printf("Failed to start PDM!");
    }

    PDM.setGain(127);

    record_ready = true;

    return true;
}

/**
 * @brief      Wait on new data
 */
static bool microphone_inference_record(void)
{
    bool ret = true;

    if (inference.buf_ready == 1) {
        ei_printf(
            "Error sample buffer overrun. Decrease the number of slices per model window "
            "(EI_CLASSIFIER_SLICES_PER_MODEL_WINDOW)\n");
        ret = false;
    }

    while (inference.buf_ready == 0) {
        delay(1);
    }

    inference.buf_ready = 0;

    return ret;
}

/**
 * Get raw audio signal data
 */
static int microphone_audio_signal_get_data(size_t offset, size_t length, float *out_ptr)
{
    numpy::int16_to_float(&inference.buffers[inference.buf_select ^ 1][offset], out_ptr, length);
    return 0;
}

/**
 * @brief      Stop PDM and release buffers
 */
static void microphone_inference_end(void)
{
    PDM.end();
    free(inference.buffers[0]);
    free(inference.buffers[1]);
    free(sampleBuffer);
}

#if !defined(EI_CLASSIFIER_SENSOR) || EI_CLASSIFIER_SENSOR != EI_CLASSIFIER_SENSOR_MICROPHONE
#error "Invalid model for current sensor."
#endif

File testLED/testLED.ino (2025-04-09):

/*
 * LED测试程序 - Arduino Nano 33 BLE
 * 用于测试四个LED灯的连接是否正常，并设置为最大亮度
 * 
 * 硬件连接:
 * - 绿灯（正常）: D2
 * - 红灯（烟雾报警器）: D3
 * - 黄灯（敲门）: D4
 * - 蓝灯（门铃）: D5
 */

// 定义LED引脚
#define GREEN_LED 2   // 绿灯（正常状态）
#define RED_LED 3     // 红灯（烟雾报警器）
#define YELLOW_LED 4  // 黄灯（敲门）
#define BLUE_LED 5    // 蓝灯（门铃）

// 亮度设置（0-255，255为最亮）
#define MAX_BRIGHTNESS 255

void setup() {
  // 初始化串口通信
  Serial.begin(9600);
  Serial.println("LED测试程序启动 - 最大亮度模式");
  
  // 设置LED引脚为输出模式
  pinMode(GREEN_LED, OUTPUT);
  pinMode(RED_LED, OUTPUT);
  pinMode(YELLOW_LED, OUTPUT);
  pinMode(BLUE_LED, OUTPUT);
  
  // 初始状态：所有LED熄灭
  digitalWrite(GREEN_LED, LOW);
  digitalWrite(RED_LED, LOW);
  digitalWrite(YELLOW_LED, LOW);
  digitalWrite(BLUE_LED, LOW);
  
  Serial.println("所有LED初始化完成");
}

void loop() {
  // 测试模式1：所有LED同时点亮（最大亮度）
  Serial.println("测试模式1：所有LED同时点亮（最大亮度）");
  
  // 使用analogWrite可以控制亮度，但Arduino Nano 33 BLE的部分引脚支持PWM
  // 如果引脚支持PWM，使用analogWrite设置最大亮度
  // 否则使用digitalWrite设置为HIGH
  
  // 由于我们要最大亮度，直接使用digitalWrite更简单
  digitalWrite(GREEN_LED, HIGH);
  digitalWrite(RED_LED, HIGH);
  digitalWrite(YELLOW_LED, HIGH);
  digitalWrite(BLUE_LED, HIGH);
  
  delay(2000);  // 等待2秒
  
  // 测试模式2：所有LED同时熄灭
  Serial.println("测试模式2：所有LED同时熄灭");
  digitalWrite(GREEN_LED, LOW);
  digitalWrite(RED_LED, LOW);
  digitalWrite(YELLOW_LED, LOW);
  digitalWrite(BLUE_LED, LOW);
  delay(1000);  // 等待1秒
  
  // 测试模式3：逐个LED点亮（最大亮度）
  Serial.println("测试模式3：逐个LED点亮（最大亮度）");
  
  // 绿灯
  Serial.println("绿灯点亮");
  digitalWrite(GREEN_LED, HIGH);
  delay(1000);
  
  // 红灯
  Serial.println("红灯点亮");
  digitalWrite(RED_LED, HIGH);
  delay(1000);
  
  // 黄灯
  Serial.println("黄灯点亮");
  digitalWrite(YELLOW_LED, HIGH);
  delay(1000);
  
  // 蓝灯
  Serial.println("蓝灯点亮");
  digitalWrite(BLUE_LED, HIGH);
  delay(1000);
  
  // 测试模式4：逐个LED熄灭
  Serial.println("测试模式4：逐个LED熄灭");
  
  // 绿灯
  Serial.println("绿灯熄灭");
  digitalWrite(GREEN_LED, LOW);
  delay(1000);
  
  // 红灯
  Serial.println("红灯熄灭");
  digitalWrite(RED_LED, LOW);
  delay(1000);
  
  // 黄灯
  Serial.println("黄灯熄灭");
  digitalWrite(YELLOW_LED, LOW);
  delay(1000);
  
  // 蓝灯
  Serial.println("蓝灯熄灭");
  digitalWrite(BLUE_LED, LOW);
  delay(1000);
}
